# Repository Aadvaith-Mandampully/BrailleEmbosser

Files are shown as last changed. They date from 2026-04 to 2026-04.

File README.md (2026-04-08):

# ⠠⠕⠏⠑⠝⠠⠑⠍⠃⠕⠎⠎  OpenEmboss DIY Braille Plotter

A fully open-source desktop braille embosser built from off-the-shelf hardware, an Arduino Mega, and a Python GUI application. Translates plain text into Grade 1 or Grade 2 UEB braille and drives a solenoid-tipped gantry to emboss raised dots onto paper.

---

## Contents

- [How it works](#how-it-works)
- [Hardware](#hardware)
- [Wiring](#wiring)
- [Repository files](#repository-files)
- [Software setup](#software-setup)
- [Firmware setup](#firmware-setup)
- [Calibration](#calibration)
- [Using the application](#using-the-application)
- [Braille geometry](#braille-geometry)
- [Serial protocol](#serial-protocol)
- [Troubleshooting](#troubleshooting)

---

## How it works

The machine has two motion axes and one embossing actuator:

- **X axis** — a NEMA17 stepper drives a T8 4-start lead screw (8 mm lead) that moves a gantry carriage across the paper width. The carriage holds the solenoid and stylus.
- **Y axis** — a second NEMA17 drives a TPU-coated rubber roller that advances the paper through the machine one dot-row at a time.
- **Solenoid** — a 12 V 42 N push-type solenoid fires the stylus downward onto a divot strip below the paper, embossing a single raised dot.

The Python application translates text to Unicode braille, computes the physical position of every raised dot in millimetres, sorts them into an efficient raster (boustrophedon snake-scan) order, and streams MOVE/DOT commands to the Arduino over USB serial. The Arduino moves both axes and fires the solenoid in response.

---

## Hardware

### Motion and structure

| Part | Specification |
|---|---|
| Fasteners | M3 and m5 Hardware|
| Heat inserts | M3 Heat set inserts, 4mm|
| Frame | 3D printed PLA side plates, 4 mm wall |
| X stepper | NEMA17, 1.7 A, 200 steps/rev |
| Y stepper | NEMA17, 1.7 A, 200 steps/rev |
| X lead screw | T8 4-start, 8 mm lead, 300 mm travel |
| X linear rod | 8 mm steel, LM8UU bearing in carriage |
| Y roller | PLA core + TPU 95A skin, 20 mm OD, 300 mm long |
| Y roller bearings | 608ZZ (×2), press-fit into roller ends |
| Pinch roller | PLA body, O-ring contact, 608ZZ bearings, spring-loaded pivot arms |
| Divot strip | Aluminium or PETG, 54 divots (27 cells × 2 columns) |
| Divot size | Ø 2.1 mm × 0.7 mm deep, hemispheric |
| Platen foam | 3 mm EVA foam backing between paper and divot strip |

### Electronics

| Part | Specification |
|---|---|
| Microcontroller | Arduino Mega 2560 |
| CNC shield | CNC Shield v3 (fits Mega header rows) |
| Stepper drivers | DRV8825 × 2, 1/16 microstepping |
| Solenoid | DC 12 V, 42 N, 10 mm stroke (JF-1253B,)|
| MOSFET driver | IRLZ44N, 100 Ω gate resistor, 1N4007 flyback diode |
| Power supply | 12 V 5 A DC |
| Endstop | Mechanical microswitch, normally-open, pin D9 |
| Paper sensor | IR break-beam or lever microswitch, pin D11 |

---

## Wiring

### CNC Shield v3 pinout (on Arduino Mega)

```
X STEP  → D2       X DIR   → D5
Y STEP  → D3       Y DIR   → D6
ENABLE  → D8       (shared, active LOW)
X-MIN   → D9       (endstop, INPUT_PULLUP, NO switch to GND)
Z-MIN   → D11      (paper sensor, INPUT_PULLUP, LOW when paper present)
D14     → 100 Ω → IRLZ44N gate   (solenoid MOSFET)
```

### DRV8825 microstepping (1/16)

Set MS1, MS2, MS3 jumpers on the CNC shield:

```
MS1 = LOW
MS2 = LOW
MS3 = HIGH
→ 1/16 microstepping
```

### MOSFET solenoid driver circuit

```
D14 ──── 100 Ω ──── IRLZ44N gate
                     IRLZ44N source → GND
                     IRLZ44N drain  → solenoid −
solenoid + → 12 V rail

10 kΩ between gate and GND  (prevents firing on boot)
1N4007 cathode → 12 V, anode → drain  (flyback protection — MANDATORY)
100 µF across 12 V/GND rails near solenoid
```

### VREF setting (do before first power-on)

With USB only (no 12 V), set VREF on each DRV8825:

```
VREF = I_rated × 0.5

For a 1.7 A motor: VREF = 0.85 V
For a 1.5 A motor: VREF = 0.75 V
For a 1.0 A motor: VREF = 0.50 V
```

Probe the trimmer pot (brass centre) with the + probe, GND with the − probe.

---

## Repository files

```
braille_plotter.ino        Arduino firmware (AccelStepper, CNC Shield pinout)
diode_test.ino             Solenoid circuit verification sketch
braille_plotter.py         Core logic: braille translator + Arduino serial interface
braille_plotter_app.py     Desktop GUI application (tkinter)
README.md                  This file
```
---

## Software setup

### Requirements

- Python 3.10 or later
- `pyserial` — the only required package

```bash
pip install pyserial
```

No other dependencies.

### Running the GUI

```bash
python braille_plotter_app.py
```

### Running the CLI terminal

```bash
python braille_terminal.py --port /dev/ttyUSB0
# Windows:
python braille_terminal.py --port COM3
```

### Running from the command line (headless)

```bash
python braille_plotter.py --port /dev/ttyUSB0 --text "Hello World"
python braille_plotter.py --port COM3 --file myfile.txt --grade 2
python braille_plotter.py --port /dev/ttyUSB0 --text "Hi" --dry-run
```

---

## Firmware setup

### Arduino IDE

1. Install [Arduino IDE 2.x](https://www.arduino.cc/en/software)
2. Install the **AccelStepper** library:
   `Sketch → Include Library → Manage Libraries → search "AccelStepper" → Install`
3. Select board: `Tools → Board → Arduino Mega or Mega 2560`
4. Select port: `Tools → Port → (your COM or /dev/tty port)`
5. Open `braille_plotter.ino` and flash

### Configuration flags in firmware

```cpp
// At the top of braille_plotter.ino:
#define USE_PAPER_SENSOR 1   // 1 = IR sensor on D11 (recommended)
                             // 0 = manual paper load (send PAPERREADY command)
```

### Steps/mm (update after calibration)

```cpp
float X_STEPS_PER_MM = 400.0;   // T8 4-start, 1/16 microstep, 200-step motor
float Y_STEPS_PER_MM = 50.93;   // 20 mm roller, 1/16 microstep, 200-step motor
```

These starting values are correct for the hardware above. Adjust after running the calibration procedure.

---

## Calibration

Calibration must be done in this exact order — each stage depends on the previous one being correct.

### Stage 1 — VREF (before 12 V power)

USB only. Set VREF on both DRV8825 drivers as described in the Wiring section. Then connect the 12 V PSU.

### Stage 2 — Solenoid circuit test

Flash `diode_test.ino`. Open serial monitor at 115200 baud. The sketch runs three tests automatically:

- **Test 1** — drain voltage at rest (~12 V) — verifies flyback diode is not shorted
- **Test 2** — single fire — verifies MOSFET switches correctly
- **Test 3** — 20-pulse burst — verifies flyback diode is present under stress

All three must print `PASS`. Then connect the solenoid and flash `braille_plotter.ino`.

### Stage 3 — Homing

Open the app, connect, go to the **Calibrate** tab, click **HOME**. The X carriage should drive left, hit the endstop on D9, back off ~0.2 mm, and stop. The console shows `Homed ✓`.

If X times out: check the endstop is wired NO (normally open) to D9 and GND. Press the switch by hand — the LED on the CNC shield should light.

### Stage 4 — X steps/mm

In the Calibrate tab, click **HOME**, then click **X +100 mm**. Measure the actual travel with calipers.

```
new_X_STEPS_PER_MM = current × (100.0 / measured_mm)
```

Update `X_STEPS_PER_MM` in `braille_plotter.ino`, reflash, repeat until within 0.1 mm over 100 mm.

Alternatively, use the **Auto-calibration** section: home, jog the carriage to a measured reference point using the jog buttons, enter the distance in mm, click **CAPTURE X**. The app reads step count from the firmware and calculates the value for you.

### Stage 5 — Y steps/mm

Insert paper. Mark the leading edge. In the Calibrate tab click **Feed 100 mm**. Measure actual paper advance with a ruler.

```
new_Y_STEPS_PER_MM = current × (100.0 / measured_mm)
```

Update `Y_STEPS_PER_MM`, reflash, repeat until within 0.2 mm over 100 mm. Always calibrate with paper loaded and the pinch roller engaged.

### Stage 6 — Paper origin

Home the machine. Jog the carriage until the stylus tip is directly above the top-left corner of the paper. Use 0.1 mm jog steps for precision. Click **SET ORIGIN**. The displayed values update in amber — copy them into `braille_plotter.py`:

```python
PAPER_ORIGIN_X = 36.000   # your measured value
PAPER_ORIGIN_Y = 0.000    # your measured value
```

### Stage 7 — Dot geometry and solenoid

**Dot spacing** — click **Dot test** in the Calibrate tab. Two dots are fired 2.5 mm apart. Measure with calipers — target 2.5 mm ± 0.05 mm.

**Cell spacing** — click **Row test**. Five cells are printed. Measure left-dot to left-dot of adjacent cells — target 6.25 mm ± 0.05 mm.

**Dot height** — fire 3 dots in a column (use the Fire Dot button + Feed 2.5 mm between each). Flip the paper and measure dot height with a feeler gauge. Target: 0.48–0.7 mm. Adjust `SOLENOID_MS` in the firmware:
- Too shallow → increase by 5 ms
- Paper tearing → decrease by 5 ms
- Start at 20 ms — the 42 N solenoid is very strong

**Alignment check** — in the Page Preview tab, click **⊕ Alignment check**. Four dots are fired at the corners of the printable area. Measure each and compare to the expected coordinates shown in the dialog.

---

## Using the application

### Print tab

1. Paste or load a `.txt` file
2. Choose Grade 1 (uncontracted) or Grade 2 (contracted)
3. Enable **Mirror** for back-face embossing (default — paper is embossed from behind, then flipped to read)
4. Click **TRANSLATE** — the braille preview and dot count update
5. Use the page navigation buttons to step through pages
6. Click **▶ PRINT ALL** to print all pages, or **▶ THIS PAGE** for the current page
7. Set X and Y speed with the sliders — adjust until motors run reliably without skipping steps

### Page Preview tab

- Shows all raised dot positions at accurate physical scale (mm)
- Rulers along top and left edges in mm, matching machine coordinates exactly
- Hover anywhere to see the cursor position and nearest dot position to 0.01 mm
- Toggle **Grid**, **Margins**, **Coords** overlays independently
- Zoom from 50% to 200%
- Orange cursor tracks the head position during printing
- **⊕ Alignment check** — fires 4 corner dots for physical verification
- **Export coords…** — saves all dot positions for the current page as CSV

### Calibrate tab

- **HOME** — homes X endstop and paper sensor, then parks head at (0.5, 0.0)
- **MOTORS OFF** — releases stepper hold current
- **FIRE DOT** — single solenoid pulse at current position
- **SET ORIGIN** — records current position as paper corner
- Jog pad — directional movement in configurable step sizes (0.1 to 10 mm)
- Quick-jog buttons — move exactly one dot pitch, cell spacing, or row spacing
- Auto-calibration — jog to reference, enter distance, click CAPTURE to compute steps/mm

### Settings tab

- Left/top margins and page width (applied on next translation)
- Rows per page (default 24 for A4 at 10.5 mm row spacing)
- Solenoid dwell time in ms

---

## Braille geometry

This machine uses non-standard large-format dimensions for enhanced tactile clarity:

| Parameter | This machine | Standard UEB |
|---|---|---|
| Dot diameter | 2.0 mm | 1.44 mm |
| Dot pitch (H & V) | 2.5 mm | 2.34 mm |
| Cell spacing | 6.25 mm | 6.2 mm |
| Row spacing | 10.5 mm | 10.0 mm |
| Cells per line (A4) | 27 | 40 |
| Rows per page (A4) | 24 | 25 |

Output is not compatible with standard braille displays or embossers. It is intended for learners or users who benefit from larger dots.

---

## Serial protocol

All commands are sent as ASCII lines at 115200 baud. The firmware replies `OK` on success or `ERR <reason>` on failure.

| Command | Description |
|---|---|
| `HOME` | Home X to endstop, establish Y=0 via paper sensor (or return immediately if USE_PAPER_SENSOR=0) |
| `PAPERREADY` | Manual mode: declare current Y position as Y=0, advance TOP_MARGIN_MM |
| `MOVE x y` | Move to absolute position in mm (Y first, then X) |
| `FEED mm` | Advance paper by mm (relative, positive = forward) |
| `DOT` | Fire solenoid once for SOLENOID_MS milliseconds |
| `SETSPEED xs ys` | Set X max speed (steps/sec) and Y max speed (steps/sec) |
| `DONE` | Disable stepper motors (releases hold current) |
| `POS` | Reply with `POS <x_steps> <y_steps>` — used for auto-calibration |

---

## Troubleshooting

**X carriage doesn't home / times out**
Check the endstop is wired normally-open between D9 and GND. Press it by hand — the X-MIN LED on the CNC shield should light. Timeout is 60 seconds.

**Motor skips steps**
Lower the X or Y speed slider. Increase VREF slightly. Check motor cable connections. Reduce solenoid firing dwell time if the solenoid and motor fire simultaneously.

**First dot in each line is missing**
The app parks the head at (0.5, 0.0) after homing to prevent this. If it still occurs, check the firmware version — the first-dot fix requires the park move in `home()`.

**Dots too shallow**
Increase `SOLENOID_MS` in the firmware by 5 ms, reflash, retest. Check foam backer is even. Ensure paper weight is 120–160 gsm.

**Dots too deep / paper tearing**
Decrease `SOLENOID_MS`. Try heavier paper. Check the stylus tip diameter — it should be 1.5 mm with a rounded profile.

**Paper skews across the page**
Check the drive roller and pinch roller are parallel. Verify both ends of the roller shaft are seated in identical Y positions in the frame. Ensure paper enters square against the registration guide.

**Columns shift right across the page**
X steps/mm is slightly low — recalibrate. Alternatively X_MAX_SPEED is too high causing missed steps — lower it.

**Rows shift down the page**
Y steps/mm is slightly low — recalibrate. Check pinch roller pressure is consistent.

**App freezes during print**
All serial communication is on a background thread — the UI should never freeze. If it does, check for an `ERR` in the console log. The most common cause is a serial timeout from a missed `OK` reply.

**`ModuleNotFoundError: No module named 'braille_plotter'`**
Both `braille_plotter.py` and `braille_plotter_app.py` must be in the same folder.

---

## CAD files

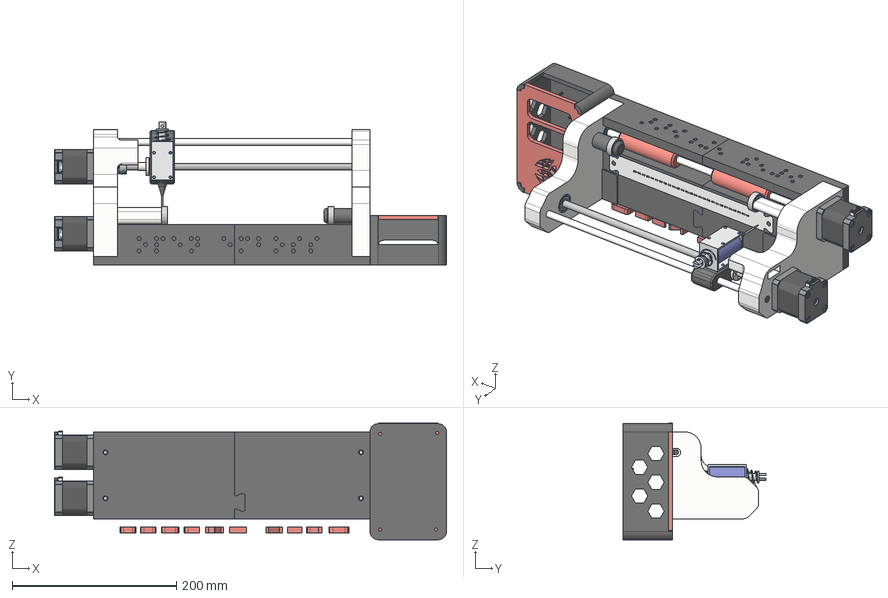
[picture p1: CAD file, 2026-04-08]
3D Models/braille+plotter.stp
477.8 x 173.8 x 142.0 mm

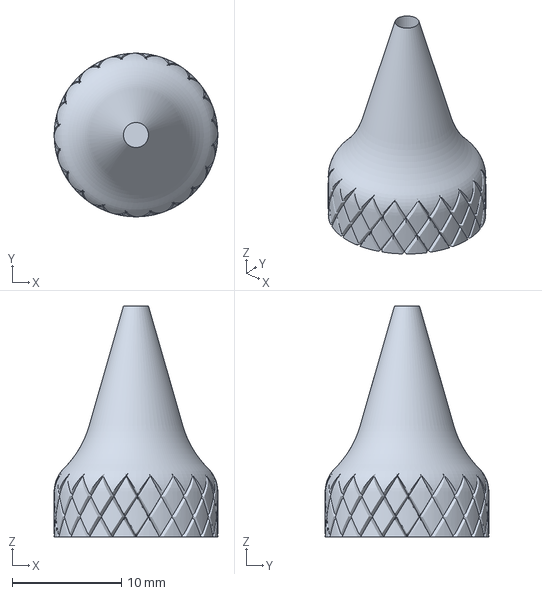
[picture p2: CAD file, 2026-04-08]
3D Models/stylus clamp.3mf
15.0 x 15.0 x 21.2 mm

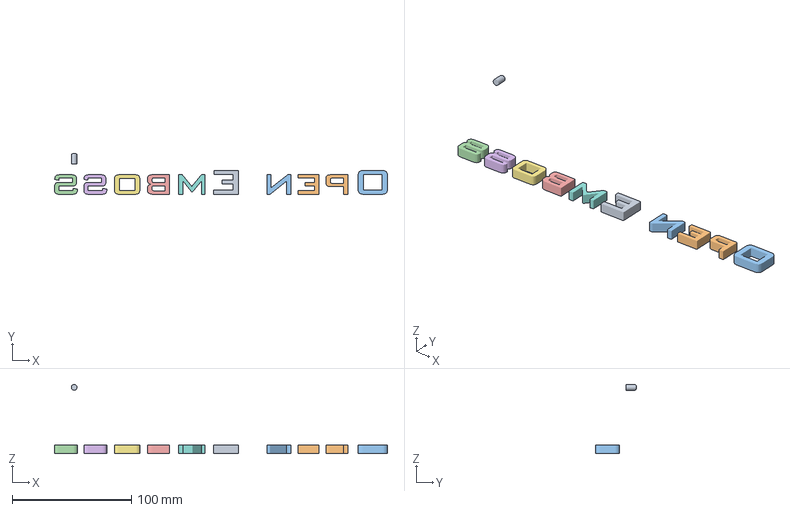
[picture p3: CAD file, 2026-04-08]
3D Models/braille nub and text inserts.3mf
279.0 x 34.0 x 57.9 mm

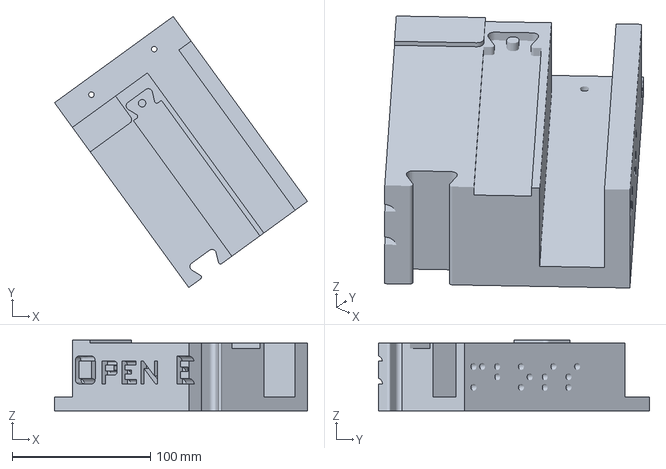
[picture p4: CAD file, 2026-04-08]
3D Models/motorized end base.3mf
182.7 x 195.8 x 51.0 mm

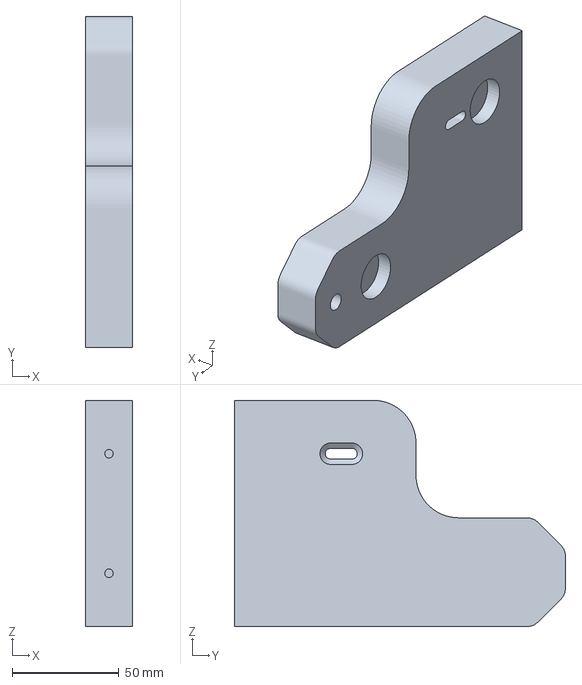
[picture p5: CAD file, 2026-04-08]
3D Models/non motorized end.3mf
22.0 x 155.0 x 106.0 mm

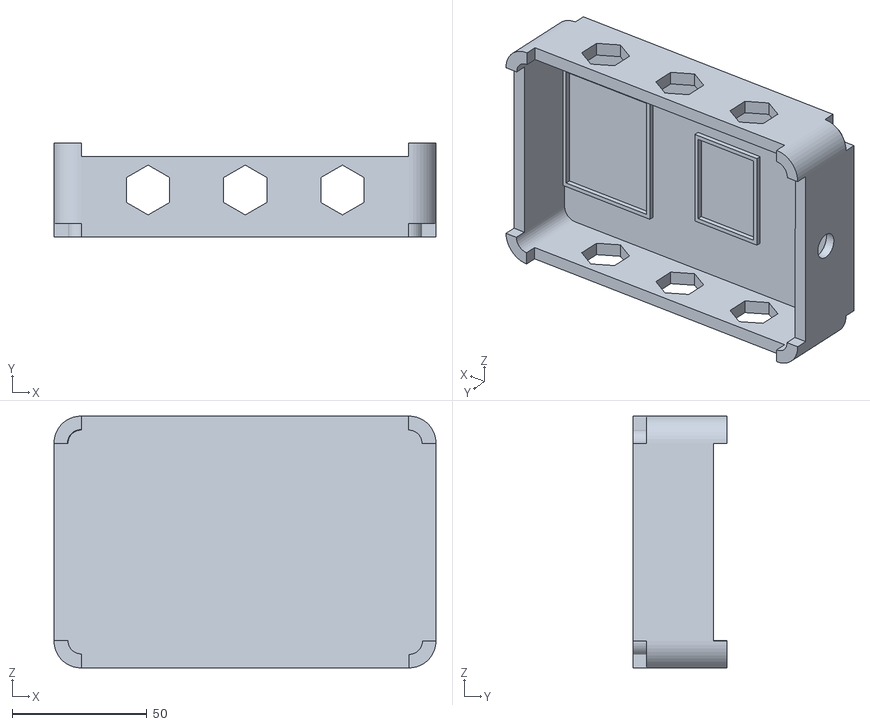
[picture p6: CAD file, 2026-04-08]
3D Models/PCB ELECTRONICS BOX.stl
141.5 x 35.0 x 93.3

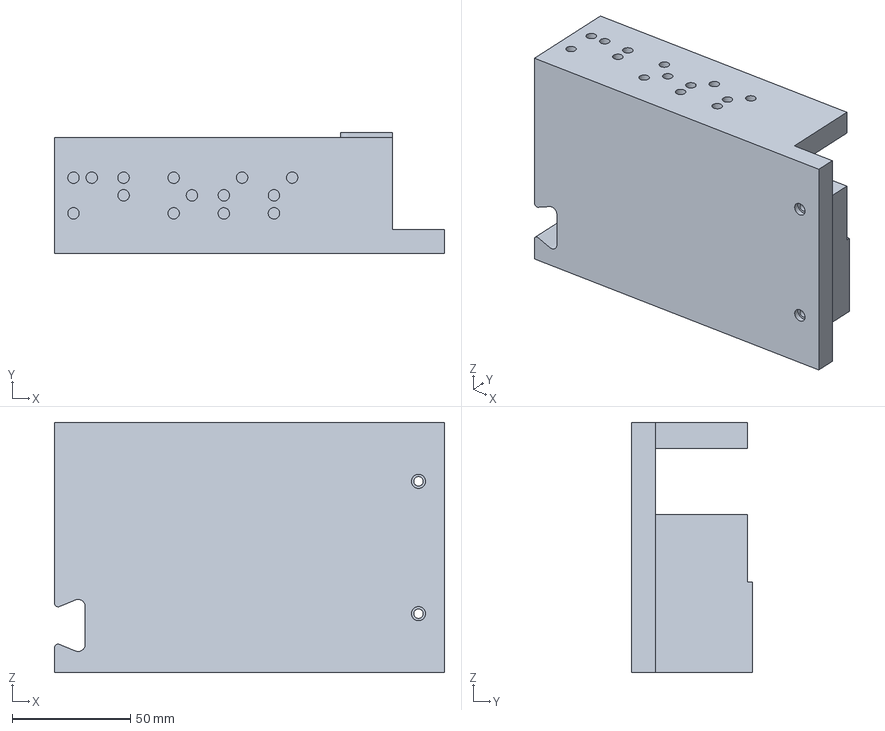
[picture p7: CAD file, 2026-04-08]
3D Models/non motorized end base.3mf
165.0 x 51.0 x 106.0 mm

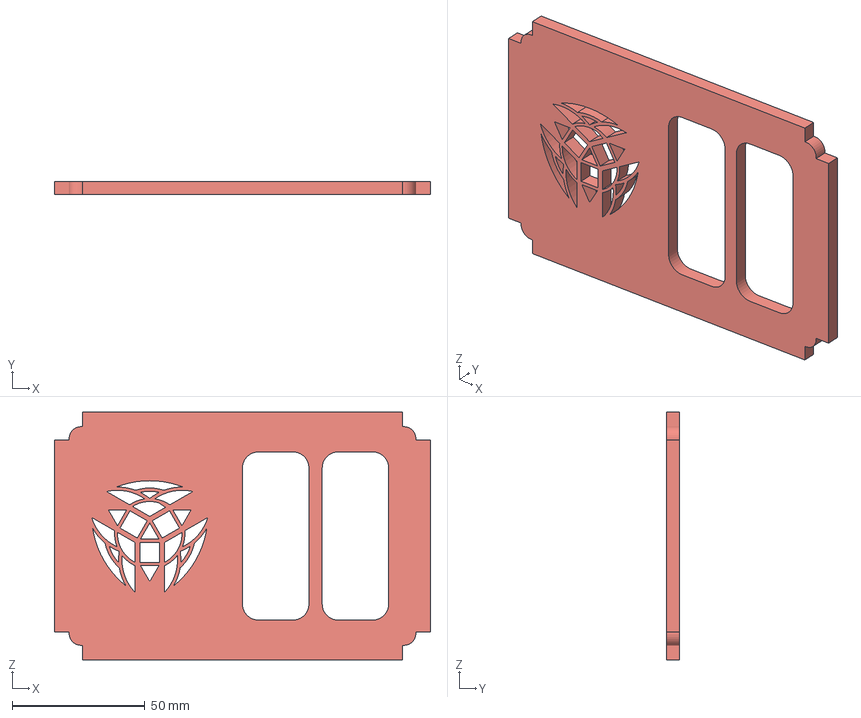
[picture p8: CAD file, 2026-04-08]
3D Models/electronics box cover.3mf
141.5 x 5.00 x 93.3 mm

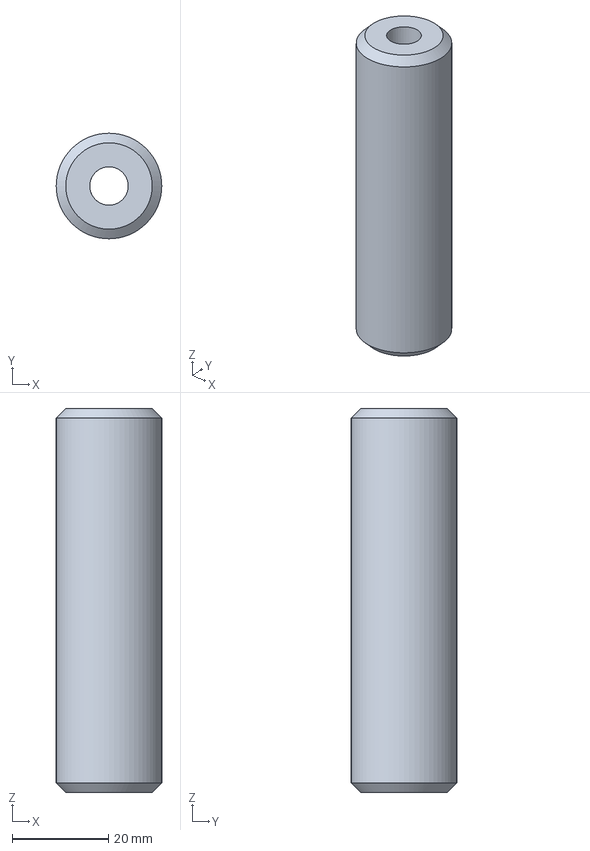
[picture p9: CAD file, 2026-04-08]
3D Models/roller tpu.3mf
22.0 x 22.0 x 80.0 mm

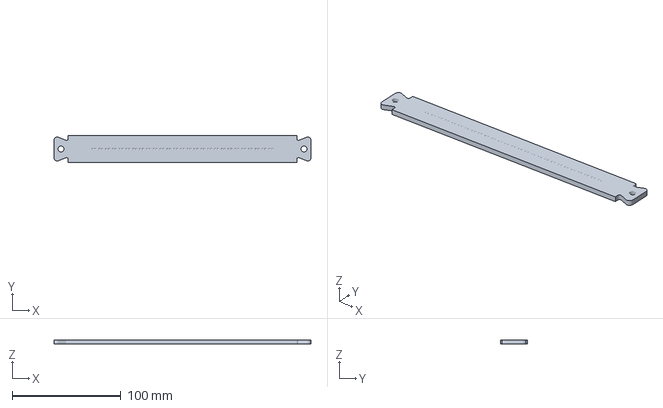
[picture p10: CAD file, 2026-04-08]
3D Models/braille divot block final.3mf
236.0 x 25.0 x 4.00 mm

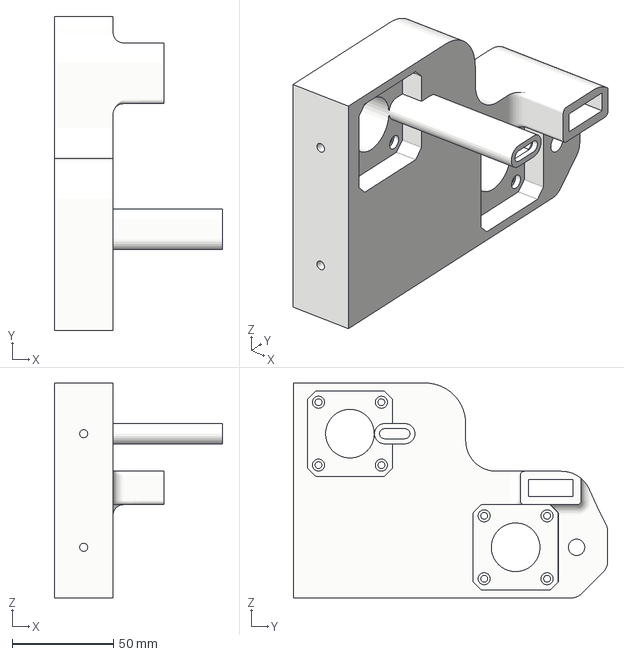
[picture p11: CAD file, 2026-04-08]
3D Models/motorized end.3mf
83.0 x 155.0 x 106.0 mm

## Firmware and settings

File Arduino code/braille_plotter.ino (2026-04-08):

#include <AccelStepper.h>

// ── Configuration ─────────────────────────────────────────────────
#define USE_PAPER_SENSOR 0

// ── Pins ──────────────────────────────────────────────────────────
#define X_STEP_PIN       2
#define X_DIR_PIN        5
#define Y_STEP_PIN       3
#define Y_DIR_PIN        6
#define ENABLE_PIN       8
#define SOLENOID_PIN     14
#define X_ENDSTOP_PIN    9
#define PAPER_SENSOR_PIN 11

// ── Motion constants ( FOR 1/16) ───────────────────────────

const float X_STEPS_PER_MM  = 400.0;
const float Y_STEPS_PER_MM  = 48;
const float X_MAX_MM = 250.0;
const float X_MAX_SPEED      = 12000.0;
const float X_ACCELERATION   = 25000.0;
const float X_HOMING_SPEED   = 5000.0;

// Y axis
const unsigned int STEP_PULSE_US  = 2;
const unsigned int Y_STEP_DELAY   = 100;
const unsigned int HOME_DELAY_US  = 600;

// Solenoid
const float        TOP_MARGIN_MM  = 10.0;
const unsigned int SOLENOID_MS    = 60;
const long         BACKOFF_STEPS  = 50;

// ── Stepper ───────────────────────────────────────────────────────
AccelStepper stepperX(AccelStepper::DRIVER, X_STEP_PIN, X_DIR_PIN);

// ── State ─────────────────────────────────────────────────────────
long currentY = 0;

// ── Motor control ─────────────────────────────────────────────────
void enableMotors() {
  digitalWrite(ENABLE_PIN, LOW);
}

void disableMotors() {
  digitalWrite(ENABLE_PIN, HIGH);
}

// ── X axis ────────────────────────────────────────────────────────
void xMoveToMM(float xMM) {
  long targetSteps = lround(xMM * X_STEPS_PER_MM);
  stepperX.moveTo(targetSteps);
  stepperX.runToPosition();
}

bool homeX() {
  stepperX.setMaxSpeed(X_HOMING_SPEED);
  stepperX.setAcceleration(X_ACCELERATION);

  stepperX.move(-1000000L);
  unsigned long startMs = millis();

  while (digitalRead(X_ENDSTOP_PIN) == HIGH) {
    if (millis() - startMs > 30000UL) return false;
    stepperX.run();
  }

  stepperX.stop();
  stepperX.setCurrentPosition(0);

  stepperX.moveTo(BACKOFF_STEPS);
  stepperX.runToPosition();
  stepperX.setCurrentPosition(0);

  stepperX.setMaxSpeed(X_MAX_SPEED);
  stepperX.setAcceleration(X_ACCELERATION);

  return true;
}

// ── Y axis ────────────────────────────────────────────────────────
void yStep(bool dir) {
  digitalWrite(Y_DIR_PIN, dir ? HIGH : LOW);

  digitalWrite(Y_STEP_PIN, HIGH);
  delayMicroseconds(STEP_PULSE_US);
  digitalWrite(Y_STEP_PIN, LOW);

  delayMicroseconds(Y_STEP_DELAY);
}

void feedPaper(float mm) {
  bool dir = (mm >= 0);
  long steps = lround(abs(mm) * Y_STEPS_PER_MM);

  for (long i = 0; i < steps; i++) {
    yStep(dir);
  }

  currentY += lround(mm * Y_STEPS_PER_MM);
}

bool homePaper() {
#if USE_PAPER_SENSOR
  unsigned long startMs = millis();

  while (digitalRead(PAPER_SENSOR_PIN) == HIGH) {
    if (millis() - startMs > 30000UL) return false;

    digitalWrite(Y_DIR_PIN, HIGH);
    digitalWrite(Y_STEP_PIN, HIGH);
    delayMicroseconds(STEP_PULSE_US);
    digitalWrite(Y_STEP_PIN, LOW);
    delayMicroseconds(HOME_DELAY_US);
  }

  feedPaper(TOP_MARGIN_MM);
  currentY = 0;
  return true;
#else
  return true;
#endif
}

// ── Solenoid ──────────────────────────────────────────────────────
void fireSolenoid() {
  digitalWrite(SOLENOID_PIN, HIGH);
  delay(SOLENOID_MS);
  digitalWrite(SOLENOID_PIN, LOW);
  delay(20);
}

// ── Move ──────────────────────────────────────────────────────────
void moveTo(float xMM, float yMM) {
  if (xMM > X_MAX_MM || xMM < 0.0) {
    Serial.println("ERR X");
    return;
  }

  long targetY = lround(yMM * Y_STEPS_PER_MM);
  long dY = targetY - currentY;

  if (abs(dY) > 0) {
    bool dir = (dY > 0);
    for (long i = 0; i < abs(dY); i++) {
      yStep(dir);
    }
    currentY = targetY;
  }

  xMoveToMM(xMM);
}

// ── Commands ──────────────────────────────────────────────────────
String inputBuffer = "";

void processCommand(String cmd) {
  cmd.trim();

  if (cmd == "HOME") {
    enableMotors();
    if (!homeX()) { Serial.println("ERR X"); return; }
    if (!homePaper()) { Serial.println("ERR Y"); return; }
    Serial.println("OK");

  } else if (cmd == "PAPERREADY") {
    enableMotors();
    feedPaper(TOP_MARGIN_MM);
    currentY = 0;
    Serial.println("OK");

  } else if (cmd.startsWith("FEED ")) {
    float mm = cmd.substring(5).toFloat();
    enableMotors();
    feedPaper(mm);
    Serial.println("OK");

  } else if (cmd.startsWith("MOVE ")) {
    int sp = cmd.indexOf(' ', 5);
    if (sp < 0) { Serial.println("ERR"); return; }

    float tx = cmd.substring(5, sp).toFloat();
    float ty = cmd.substring(sp + 1).toFloat();

    enableMotors();
    moveTo(tx, ty);
    Serial.println("OK");

  } else if (cmd == "DOT") {
    fireSolenoid();
    Serial.println("OK");

  } else if (cmd.startsWith("DWELL ")) {
    delay(cmd.substring(6).toInt());
    Serial.println("OK");

  } else if (cmd == "DONE") {
    disableMotors();
    Serial.println("OK");

  } else {
    Serial.println("ERR");
  }
}

// ── Setup ─────────────────────────────────────────────────────────
void setup() {
  pinMode(X_STEP_PIN, OUTPUT);
  pinMode(X_DIR_PIN, OUTPUT);
  pinMode(Y_STEP_PIN, OUTPUT);
  pinMode(Y_DIR_PIN, OUTPUT);
  pinMode(ENABLE_PIN, OUTPUT);
  pinMode(SOLENOID_PIN, OUTPUT);
  pinMode(X_ENDSTOP_PIN, INPUT_PULLUP);
  pinMode(PAPER_SENSOR_PIN, INPUT_PULLUP);

  disableMotors();

  stepperX.setMaxSpeed(X_MAX_SPEED);
  stepperX.setAcceleration(X_ACCELERATION);

  Serial.begin(115200);
  Serial.println("OK READY");
}

// ── Loop ──────────────────────────────────────────────────────────
void loop() {
  while (Serial.available()) {
    char c = Serial.read();

    if (c == '\n') {
      processCommand(inputBuffer);
      inputBuffer = "";
    } else if (c != '\r') {
      inputBuffer += c;
    }
  }
}

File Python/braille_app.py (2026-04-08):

#!/usr/bin/env python3
"""
Braille Plotter — Desktop Application
=======================================

Requirements:  pip install pyserial
               braille_plotter.py in the same folder
"""

import tkinter as tk
from tkinter import ttk, filedialog, messagebox, scrolledtext
import threading
import queue
import time
import math
import serial
import serial.tools.list_ports
import sys
import os

sys.path.insert(0, os.path.dirname(__file__))
try:
    import braille_plotter as bp
except ImportError:
    messagebox.showerror("Missing file", "braille_plotter.py must be in the same folder.")
    sys.exit(1)


# ─────────────────────────────────────────────────────────────────
#  MULTI-PAGE SPLITTER
# ─────────────────────────────────────────────────────────────────

def split_into_pages(braille_text: str,
                     rows_per_page: int = 25) -> list[str]:
    """
    Split a braille string into page-sized chunks.
    Each chunk is a string of braille characters with embedded newlines.
    rows_per_page: standard A4 = 25 rows at 10 mm row spacing with 20 mm margins.
    """
    pages = []
    current_page_rows = []
    current_row_cells = 0
    current_row_chars = []
    in_number = False

    for ch in braille_text:
        if ch == '\n':
            current_page_rows.append(''.join(current_row_chars) + '\n')
            current_row_chars = []
            current_row_cells = 0
            if len(current_page_rows) >= rows_per_page:
                pages.append(''.join(current_page_rows))
                current_page_rows = []
            continue

        current_row_chars.append(ch)
        current_row_cells += 1

        if current_row_cells >= bp.CELLS_PER_LINE:
            current_page_rows.append(''.join(current_row_chars) + '\n')
            current_row_chars = []
            current_row_cells = 0
            if len(current_page_rows) >= rows_per_page:
                pages.append(''.join(current_page_rows))
                current_page_rows = []

    # Flush remainder
    if current_row_chars:
        current_page_rows.append(''.join(current_row_chars))
    if current_page_rows:
        pages.append(''.join(current_page_rows))
    if not pages:
        pages = ['']

    return pages


def dots_for_page(page_braille: str,
                  boustrophedon: bool = True,
                  mirror: bool = True) -> list[tuple[float, float]]:
    """Generate dot jobs for one page of braille text."""
    return bp.braille_to_dot_jobs(page_braille,
                                  boustrophedon=boustrophedon,
                                  mirror=mirror)


# ─────────────────────────────────────────────────────────────────
#  SERIAL WORKER
# ─────────────────────────────────────────────────────────────────

class SerialWorker(threading.Thread):
    def __init__(self, log_queue):
        super().__init__(daemon=True)
        self.log_q  = log_queue
        self.cmd_q  = queue.Queue()
        self.conn   = None
        self.running = True
        self.status  = "disconnected"
        self.pos_x   = 0.0
        self.pos_y   = 0.0
        self._abort  = threading.Event()

    def connect(self, port, baud=115200):
        try:
            self.conn = serial.Serial(port, baudrate=baud, timeout=30)
            self.log(f"Opened {port}")
            deadline = time.time() + 8.0
            while time.time() < deadline:
                raw = self.conn.readline()
                if b"READY" in raw:
                    self.status = "idle"
                    self.log("Arduino ready ✓")
                    return True
            self.log("WARNING: no READY signal — proceeding anyway")
            self.status = "idle"
            return True
        except Exception as e:
            self.log(f"Connection failed: {e}")
            self.status = "disconnected"
            return False

    def disconnect(self):
        if self.conn and self.conn.is_open:
            try: self._send_raw("DONE")
            except Exception: pass
            self.conn.close()
        self.status = "disconnected"
        self.log("Disconnected")

    def _send_raw(self, cmd):
        if not self.conn or not self.conn.is_open:
            raise IOError("Not connected")
        self.conn.write((cmd + "\n").encode("ascii"))
        self.conn.flush()
        while True:
            raw = self.conn.readline()
            if not raw:
                raise IOError(f"Timeout on: {cmd}")
            reply = raw.decode("ascii", errors="ignore").strip()
            if reply == "OK": return "OK"
            if reply.startswith("ERR"): raise RuntimeError(reply)

    def send(self, cmd):
        self.log(f"→ {cmd}")
        result = self._send_raw(cmd)
        self.log(f"← {result}")
        return result

    def home(self):
        self.status = "busy"
        self.log("Homing (X endstop + paper sensor if enabled)…")
        self.send("HOME")
        self.pos_x = 0.0
        self.pos_y = 0.0
        self.status = "idle"
        self.log("Homed ✓  position reset to (0, 0)")

    def move_to(self, x, y):
        self.send(f"MOVE {x:.4f} {y:.4f}")
        self.pos_x = x
        self.pos_y = y

    def jog(self, dx, dy):
        self.move_to(self.pos_x + dx, self.pos_y + dy)

    def fire_dot(self):
        self.send("DOT")

    def feed(self, mm):
        self.send(f"FEED {mm:.4f}")
        self.pos_y += mm

    def set_origin(self):
        bp.PAPER_ORIGIN_X = self.pos_x
        bp.PAPER_ORIGIN_Y = self.pos_y
        self.log(f"Paper origin set: X={bp.PAPER_ORIGIN_X:.3f}  Y={bp.PAPER_ORIGIN_Y:.3f}")

    def paper_ready(self):
        self.send("PAPERREADY")
        self.pos_y = 0.0

    def motors_off(self):
        self.send("DONE")
        self.status = "idle"

    def print_page(self, dot_jobs, progress_cb=None):
        self.status = "printing"
        self._abort.clear()
        total = len(dot_jobs)
        for i, (x_mm, y_mm) in enumerate(dot_jobs, 1):
            if self._abort.is_set():
                self.status = "idle"
                return False
            self.move_to(x_mm, y_mm)
            self.fire_dot()
            if progress_cb:
                progress_cb(i, total)
        self.status = "idle"
        return True

    def abort(self):
        self._abort.set()
        self.log("Abort requested…")

    def log(self, msg):
        ts = time.strftime("%H:%M:%S")
        self.log_q.put(f"[{ts}]  {msg}")

    def enqueue(self, fn):
        self.cmd_q.put(fn)

    def run(self):
        while self.running:
            try:
                fn = self.cmd_q.get(timeout=0.1)
                fn()
            except queue.Empty:
                pass
            except Exception as e:
                self.log(f"Error: {e}")
                self.status = "idle"

    def stop(self):
        self.running = False
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

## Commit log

2026-04-08 Add Braille plotter functionality
    Implement a Braille plotter in Python that translates text to Braille and interfaces with an Arduino for embossing.
2026-04-08 Arduino Code
2026-04-08 README for Braille Plotter project
    Updated project description and added detailed sections on hardware, wiring, software setup, calibration, and troubleshooting for the DIY Braille Plotter.
